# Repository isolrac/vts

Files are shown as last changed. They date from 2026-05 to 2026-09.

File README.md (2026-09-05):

# vts

A DIY open-source wearable device for vibrotactile stimulation (VTS) therapy for spasmodic dysphonia, based on research at the University of Minnesota.

---

## Overview

Spasmodic dysphonia is a neurological voice disorder that causes involuntary spasms in the throat muscles during speech, resulting in a strained or broken voice. The standard treatment is Botox injections, offering temporary relief.

Researchers at the University of Minnesota have shown that placing small vibration motors against the skin over the voice box can produce short-term improvements in voice quality and ease of speaking by "[modulating] neruonal synchonization over sensorimotor cortex". This project is a DIY functional equivalent of the wearable device used in those studies, built for personal in-home use.

This project is independent from and is not affiliated with the aforementioned university, team, or individuals.

---

## Foundational Research

1. **Proof-of-concept feasibility study (2019)**
   Konczak et al. — *Scientific Reports*
   Single-session VTS (29 min); 13 participants with adductor LD.
   → https://www.nature.com/articles/s41598-019-54396-4

2. **UMN Lab overview — laryngeal vibration research**
   Overview of the VTS research program and links to publications.
   → https://hsc.umn.edu/vibro-tactile-stimulation-topic/laryngeal-vibration-treatment-voice-disorder

3. **11-week randomized controlled trial (2024)**
   Konczak et al. — *Frontiers in Neurology* (ClinicalTrials.gov: NCT03746509)
   39 participants; crossover design; 40 Hz and 100 Hz; self-administered in-home.
   → https://www.frontiersin.org/journals/neurology/articles/10.3389/fneur.2024.1403050/full

4. **In-home usability and feasibility study (2025)**
   Amini et al. — *Journal of Voice*
   Self-administered in-home VTS; usability and feasibility outcomes.
   → https://www.sciencedirect.com/science/article/abs/pii/S0892199725003297

---

## System Architecture

```

┌──────────────────────────┐
│  Collar Hardware         │  2× ERM vibration motors at thyroid cartilage
│  XIAO nrF + DRV8833      │  PWM control, LiPo power, battery monitoring
└────────────┬─────────────┘
             │ Bluetooth Low Energy (BLE)
             │ custom GATT characteristic
┌────────────▼─────────────┐
│  Web UI                  │  Speed slider, connect/disconnect
│  GitHub Pages (HTTPS)    │  Loads once, then works offline
│  Chrome / Bluefy         │  Web Bluetooth API
└──────────────────────────┘
```

## Charging / Power overview
```
                         USB-C
                           |
                           v
              +----------------------------+
              |     XIAO nRF52840          |
              |  (onboard USB charger)     |
              +-------------+--------------+
                            | BAT pad (shared VBAT node)
              +-------------+---------------+
              |                             |
              v                             v
    [ SW1 power switch ]              [ 3.3v buck ]
              |                             |
              v                             |
  [ protected 1S 2200 mAh                   v
    Li-ion battery ]              [C1 220 uF + C2 10 uF decoupling caps]
                                            |
                                            v
                                    [ DRV8833 motor driver ]
      XIAO control I/O:                |          |
      | D2 / PWM         ------------> |          |
      | D1 / nFAULT      <------------ |          |
      | 3V3 / nSLEEP + pull-up ------> |          |
      | GND                            |          |
      +----------- common GND ---------+          |
                                       |          |
                             24-26 AWG twisted pairs
                                       |          |
                                 [Motor 1]    [Motor 2]
                                  C3 100 nF    C4 100 nF snubber caps
                                 at terminals  at terminals
```
---

## Hardware

### Bill of Materials

| Component | Description | Notes |
|---|---|---|
| Seeed Studio XIAO nRF52840 | Microcontroller | non-Sense variant; CircuitPython 10.2.x |
| AILUOMI DRV8833 breakout | Motor driver | Active-low nFAULT wired to XIAO D1 through R1 |
| 3.3 V buck | Motor regulator | ~2 A capable; enters 100% duty near end of discharge, so the motor rail sags with the battery from that point on |
| Adafruit 1781 | Protected 1S 2200 mAh Li-ion battery | |
| 2x Vybronics VZ7AL2B169208T | ERM vibration motors | 7x25mm cylinder |
| Panasonic EEUFR1A221 | 220 uF driver bulk cap (C1) | electrolytic decoupling cap |
| 10 uF tantalum, >=10 V rating | Driver bulk cap (C2) | tantalum decoupling cap |
| 2x 100 nF X7R ceramic | Motor snubber caps (C3, C4) | soldered across motor terminals |
| 10k Ohm through-hole resistor | 10 kohm nFAULT pull-up resistor (R1) | Pulls DRV8833 nFAULT to XIAO 3V3 |

> **Note:** This BOM is a work in progress. Everything listed was available from DigiKey in the U.S. at the time of this writing

- The MCU drives both ERM motors together through the DRV8833 from a single PWM pin.
- A 3.3 V buck regulator supplies the motor rail from the protected LiPo, and the DRV8833's active-low nFAULT is monitored on XIAO D1.
- Motor spec sheet lists 3.6V max at the motor terminals, and there's some voltage drop over the 3 feet of motor wiring, so we're within tolerances.

### Enclosure / Housing

- 3D printed enclosures for the motors and main unit, customizable to the diameter and length of the ERM motors used, are included in this repository.
- The bulk of the circuitry and battery lives in an external enclosure carried in the user's pocket. Silicone-coated wires powering each motor are twisted into a pair to mitigate interference alongside a length of unextruded TPU to lend mechanical strength, and heat-shrunk together at a few junctures just to keep the bundle cohesive. Each motor is in its own minimal housing that can be quickly put on and removed, reducing bulk around the user's neck.
- **Motor cabling:** 24-26 AWG stranded copper, twisted pair per motor, with mechanical strain relief. Route motor wiring clear of external antenna / USB socket.

---

## Firmware

### Requirements

- CircuitPython 10.2.x for XIAO nRF52840
- CircuitPython libraries: `adafruit_ble`, `adafruit_ble_radio`

### Installation

- flash the MCU with the circuitpython firmware image (https://circuitpython.org/board/Seeed_XIAO_nRF52840_Sense/)
- The MCU should now be mounted as a writeable drive
- Copy `code.py` to the root of the `CIRCUITPY` drive. On boot, the device immediately begins advertising over BLE.
- Download the libraries from the above circuitpython link and copy the libraries used to the MCU as well.

### Key Behaviors

**PWM motor control**
- Pin: `board.D2`
- Frequency: 1000 Hz
- Resolution: 16-bit duty cycle
- Both motors run identically from a single PWM signal through both DRV8833 channels

### BLE / GATT

The device advertises a custom GATT service. The client writes motor speed as a uint8 percentage to the speed characteristic and subscribes to device status notifications.

| | UUID |
|---|---|
| Service | `30c41c6a-fb6d-43f6-9452-360b85ebc2c2` |
| Speed characteristic | `895a81a6-01a7-4643-b93b-e5969464ab83` |
| Device status characteristic | `fb9eb7c9-7720-48bd-923e-c0f53174d950` |

**Speed:** uint8, write, range 0 (stopped) to 100 (full speed).

**Device status:** 5 bytes, little-endian, read/notify.

| Bytes | Type | Field |
|---|---|---|
| 0-1 | uint16 | Battery voltage in mV |
| 2 | uint8 | Speed percent (0-100) |
| 3 | uint8 | Battery critical flag (0 or 1) |
| 4 | uint8 | Motor fault latched (0 or 1) |

---

## Usage

1. Position the motors against the left and right lateral edges of your thyroid cartilage
2. Open the Web UI <https://isolrac.github.io/vts/mcu_code/> in Chrome on your mobile device
3. Tap **Connect** and pair with `vts`
4. Use the speed slider to set motor intensity
5. Tap **Disconnect** when done.

**Recommended usage (from in-home feasibility study):** 3 sessions per week for the first month, increasing as tolerated.

---

## Disclaimer

This is a personal research project. It is not a medical device, and I am not a Doctor of Medicine. Use at your own risk.

---

## Roadmap / Known Issues

- **iOS Web Bluetooth** — Safari does not support Web Bluetooth
- **Voice activity detection (VAD)** — The lab device can trigger motors only during active vocalization using a neck-contact accelerometer; this project currently uses always-on continuous stimulation, which is also supported by the clinical evidence

---

## License

MIT License — see `LICENSE` for details.

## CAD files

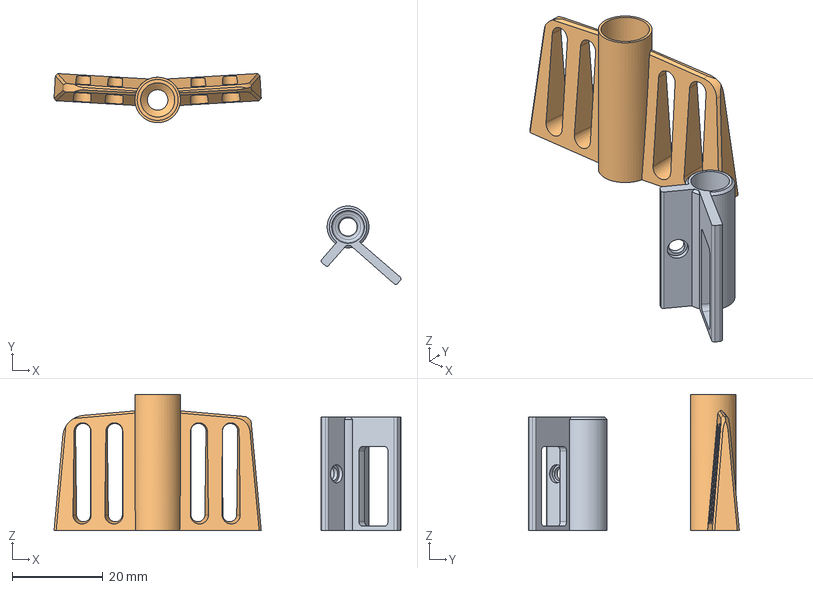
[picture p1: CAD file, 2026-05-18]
enclosure/vts_bare_motor_pin.step
76.3 x 46.4 x 30.0 mm

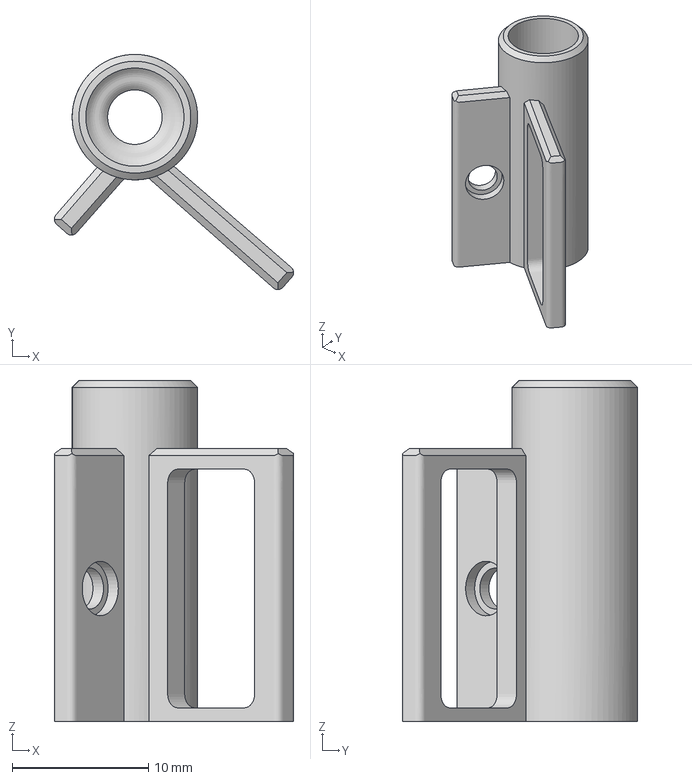
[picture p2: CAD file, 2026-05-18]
enclosure/pin-a4-fillet.3mf
17.5 x 17.2 x 25.0 mm

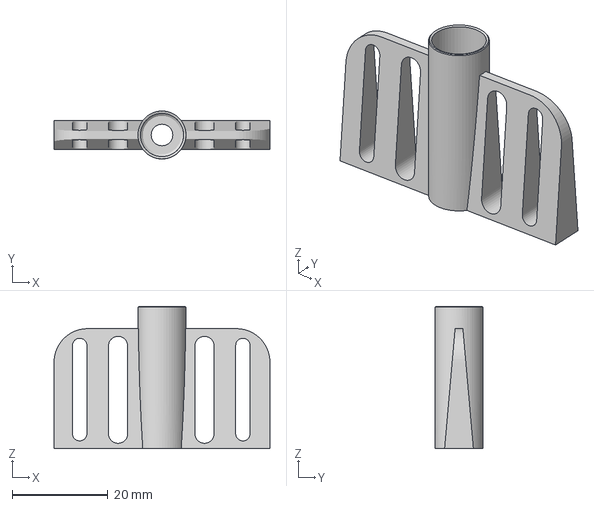
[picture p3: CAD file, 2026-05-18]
enclosure/pin-b8-large.3mf
45.0 x 10.00 x 29.6 mm

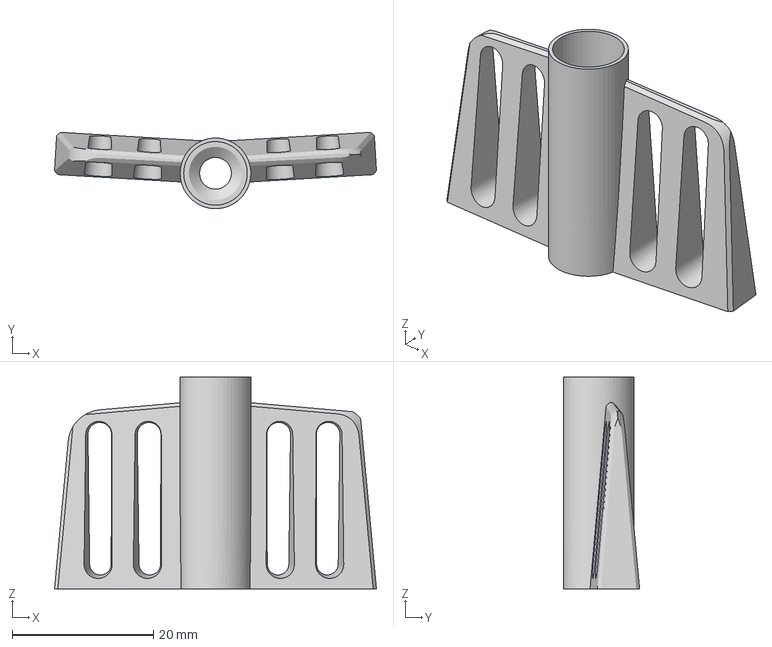
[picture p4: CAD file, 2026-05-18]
enclosure/pin-c-4.3mf
45.6 x 10.8 x 30.0 mm

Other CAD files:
enclosure/vts_bare_motor_pin.stl

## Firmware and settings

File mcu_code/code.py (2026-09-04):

import struct
import time
import board
import digitalio
import pwmio
import analogio
from adafruit_ble import BLERadio
from adafruit_ble.advertising.standard import ProvideServicesAdvertisement
from adafruit_ble.services import Service
from adafruit_ble.characteristics import Characteristic
from adafruit_ble.characteristics.int import Uint8Characteristic
from adafruit_ble.uuid import VendorDefinedUUID

# ----- Configuration -----

NFAULT_PIN = board.D2  # active-low DRV8833 nFAULT (blue wire); external 10k pull-up on the schematic
PWM_PIN = board.D4  # GPIO pin driving both DRV8833 IN lines (yellow wire)
NSLEEP_PIN = board.D5  # DRV8833 nSLEEP (green wire); active-low: high=enable, low=sleep/coast

PWM_FREQ = 1000  # Hz

BATTERY_ADC_PIN = board.VBATT  # XIAO nRF52840 internal VBAT sense (P0.31)
BATTERY_ENABLE_PIN = board.READ_BATT_ENABLE  # drive low to power the divider (P0.14)
# ponytail: nominal 1M/510k divider ratio; trim against a multimeter if voltage reads off.
BATTERY_DIVIDER_RATIO = (1000.0 + 510.0) / 510.0

ADC_MAX = 65535

ADC_OVERSAMPLE = 16

BATTERY_SAMPLE_INTERVAL = 0.5  # seconds

# LDO dropout at 3.18V, hard cutoff at 3.1V
LDO_DROPOUT = 3.18
BATTERY_CUTOFF = 3.1

# ----- GATT Service -----
#
# Speed char        (client -> device): uint8, 0-100 %
# Device status char (device -> client): 5 bytes little-endian
#   [0:2] battery voltage in mV  (uint16)
#   [2]   speed percent          (uint8)
#   [3]   battery critical flag  (uint8, 0 or 1)
#   [4]   motor fault latched    (uint8, 0 or 1)

_SVC_UUID = VendorDefinedUUID("30c41c6a-fb6d-43f6-9452-360b85ebc2c2")
_SPEED_UUID = VendorDefinedUUID("895a81a6-01a7-4643-b93b-e5969464ab83")
_DEVICE_STATUS_UUID = VendorDefinedUUID("fb9eb7c9-7720-48bd-923e-c0f53174d950")


class VTSService(Service):
    uuid = _SVC_UUID
    speed = Uint8Characteristic(
        uuid=_SPEED_UUID,
        properties=Characteristic.WRITE | Characteristic.WRITE_NO_RESPONSE,
        initial_value=0,
    )
    device_status = Characteristic(
        uuid=_DEVICE_STATUS_UUID,
        properties=Characteristic.READ | Characteristic.NOTIFY,
        max_length=5,
        fixed_length=True,
        initial_value=bytes(5),
    )


# ----- Hardware init -----

pwm = pwmio.PWMOut(PWM_PIN, duty_cycle=0, frequency=PWM_FREQ)

# DRV8833 nSLEEP is active-low. Hold the driver asleep (outputs Hi-Z) through
# boot, then wake it once the rails have settled.
nsleep = digitalio.DigitalInOut(NSLEEP_PIN)
nsleep.direction = digitalio.Direction.OUTPUT
nsleep.value = False  # asleep until rails settle

_batt_enable = digitalio.DigitalInOut(BATTERY_ENABLE_PIN)
_batt_enable.direction = digitalio.Direction.OUTPUT
_batt_enable.value = False  # active-low: pull low to connect the VBAT divider
adc = analogio.AnalogIn(BATTERY_ADC_PIN)

# R1 (10k) supplies the external pull-up; no internal pull needed.
nfault = digitalio.DigitalInOut(NFAULT_PIN)
nfault.direction = digitalio.Direction.INPUT

time.sleep(0.1)  # let supply rails settle before any motor current flows
nsleep.value = True  # nSLEEP high: enable the DRV8833

# ----- BLE init -----

ble = BLERadio()
ble.name = "VTS"
vts_service = VTSService()
advertisement = ProvideServicesAdvertisement(vts_service)

# ----- State -----

target_duty = 0.0
battery_critical = False
motor_fault_latched = False  # set on active-low nFAULT; cleared only by power cycle
last_battery_time = time.monotonic()
_battery_voltage = 3.7  # cached battery voltage; initialised to a safe mid-range value
_advertising = False

# ----- Battery -----


def battery_read_voltage():
    total = sum(adc.value for _ in range(ADC_OVERSAMPLE))
    adc_voltage = (total / ADC_OVERSAMPLE) / ADC_MAX * adc.reference_voltage
    return adc_voltage * BATTERY_DIVIDER_RATIO


def battery_is_critical(battery_voltage):
    return battery_voltage <= BATTERY_CUTOFF


# ----- Motor -----


def motor_update_battery(voltage):
    global _battery_voltage
    _battery_voltage = voltage


def motor_set_duty(target):
    effective = target
    if _battery_voltage < LDO_DROPOUT:
        # Boost duty to compensate for reduced motor voltage when LDO sags
        effective = target * (LDO_DROPOUT / _battery_voltage)
    effective = max(0.0, min(1.0, effective))
    pwm.duty_cycle = int(effective * 65535)


def motor_stop():
    pwm.duty_cycle = 0


# ----- Status characteristic -----


def push_status():
    battery_voltage_millivolts = int(_battery_voltage * 1000)
    speed_percent = int(target_duty * 100)
    critical = 1 if battery_critical else 0
    fault = 1 if motor_fault_latched else 0
    vts_service.device_status = struct.pack("<HBBB", battery_voltage_millivolts, speed_percent, critical, fault)


# ----- Main loop -----

print("Starting BLE advertising as VTS")

try:
    while True:
        if not ble.connected:
            motor_stop()  # stop motors whenever the client disconnects
            if not _advertising:
                ble.start_advertising(advertisement)
                _advertising = True
            time.sleep(0.01)
            continue

        # First connection event: stop advertising
        if _advertising:
            ble.stop_advertising()
            _advertising = False

        # Active-low DRV8833 fault: latch and keep motors off until power cycle.
        if not nfault.value:
            motor_fault_latched = True

        if motor_fault_latched:
            motor_stop()
            push_status()
            continue

        # Apply speed written by the client
        percent = vts_service.speed
        if percent is not None:
            target_duty = max(0, min(100, int(percent))) / 100.0

        now = time.monotonic()

        if now - last_battery_time >= BATTERY_SAMPLE_INTERVAL:
            last_battery_time = now
            battery_voltage = battery_read_voltage()

            if battery_is_critical(battery_voltage):
                battery_critical = True
                motor_stop()
                push_status()
                continue

            battery_critical = False
            motor_update_battery(battery_voltage)
            push_status()

        if battery_critical:
            continue

        motor_set_duty(target_duty)
finally:
    motor_stop()

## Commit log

2026-05-18 Initial project commit - add design file and circuitpython prototypes
    [pin-a4-fillet.3mf, pin-b8-large.3mf, pin-c-4.3mf]
2026-05-18 More 3dp formats for modification/webview
    [vts_bare_motor_pin.step, vts_bare_motor_pin.stl]
2026-05-19 Refactor to use BLE Publish critical device info over BLE (instead of the ESP32 to serve up an adhoc webpage) to improve battery life
2026-06-15 use on-chip adc
2026-08-26 use sensed adc ref voltage
2026-08-26 Update block schematics to reflect updated wiring
2026-09-04 update firmware pin assignments to as-wired
